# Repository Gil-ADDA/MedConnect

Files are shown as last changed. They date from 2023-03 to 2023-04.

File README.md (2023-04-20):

# MedConnect: A Compact and Efficient Pill Organizer for Seniors

## Introduction

The purpose of this project is to design and build a set of devices that solve various compounding problems faced by older generations - those being the consumption of prescribed medication in a timely manner, and also frequent isolation from loved ones.

This project serves different purposes for each user. For the patient and their device, it serves as a central device to organize their medication, as well as a reminder to take their medication. For the relative or carer and their device, it provides the knowledge that your loved one or patient is taking their medication properly, or serves as a means to remind them to do so if they forget. For both groups, it provides comfort and connection, illustrating that your loved ones are there for you even when they're physically absent.

The main features of this project are specific to each device. With their device, the patient has the ability to organize a week's worth of medication into daily boxes and, by the act of taking their medication, notify their relative of carer that they have done this. It also has the ability to receive notifications from the relative or carer device and use a buzzer to notify the patient if they have not taken their medication. The relative or carer device has the ability to recieve notifications from the patient device once medication has been taken, as well as remind the patient to take their medication through the push of a button.

## Second Midterm Critique

The feedback our team recieved in our second midterm critique is as follows:
- Change the way the pill boxess will be detected - turning them into the equivilant of a switch, this allowed our team to use a digital pin each for the 7 pill boxes instead of having to split anolog pins between 2 pill boxes in our previous design. 
-  Add communication button to the relative device in order to nudge the user to take medication if they haven't, also lets the user know they're relative or carer is thinking baout them.
- Add rails to the pill box and daily boxes so they fit together correctly.

## Prototyping

MedConnect was created to provide seniors with an effective solution to manage their medication needs, while also providing peace of mind to their family members. Initially, we implemented bare conductive sensors to detect pressure on pill boxes, but we found that they were not accurate enough. We then tried using a 1kg load cell, but it proved to be difficult to measure milligrams precisely. Eventually, we decided to use copper foil to detect each daily pill box. Our original plan involved sliding pill boxes and displaying medication reminders on an LCD screen.

During the development of the first printing, we made several iterations to improve its design and functionality. We received feedback about the initial size and material waste of the first printing, which prompted us to make adjustments to reduce the size of the box while still maintaining ergonomic and practical considerations. The second version of the box was successfully resized to fit comfortably in the hand and allowed for efficient storage of pills, while also being proportional to the copper foils and electrical wires. The third and final version addressed concerns about copper foil damage and the need for sufficient space for magnets to secure the small boxes. These modifications made the box more user-friendly, with improved circuit stability and a secure magnet system. The overall result is a compact and efficient pill organizer that is easy to use and troubleshoot.

Below are images showing the development process of MedConnect from its initial prototype to the final product:

### Drawing of the Pill Organizer
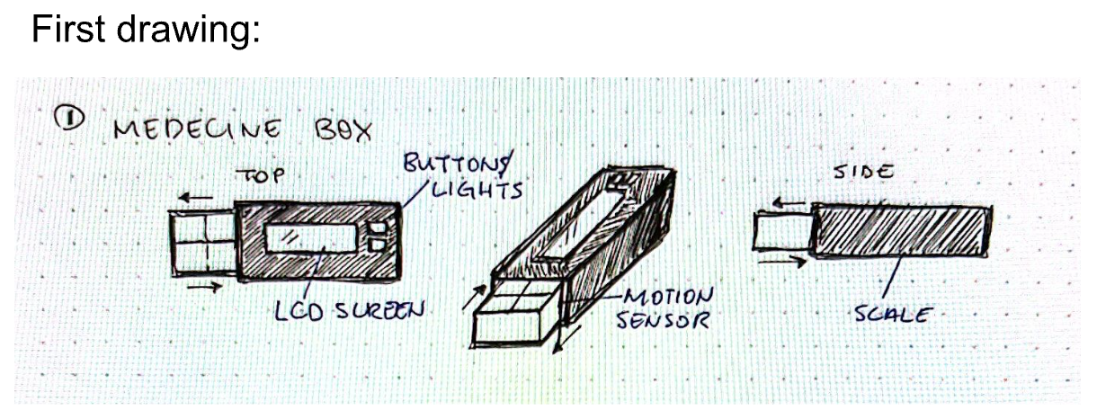
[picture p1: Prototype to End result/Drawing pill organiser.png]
Drawing of the Pill Organizer


### First Prototype - Bare Conductive Sensors
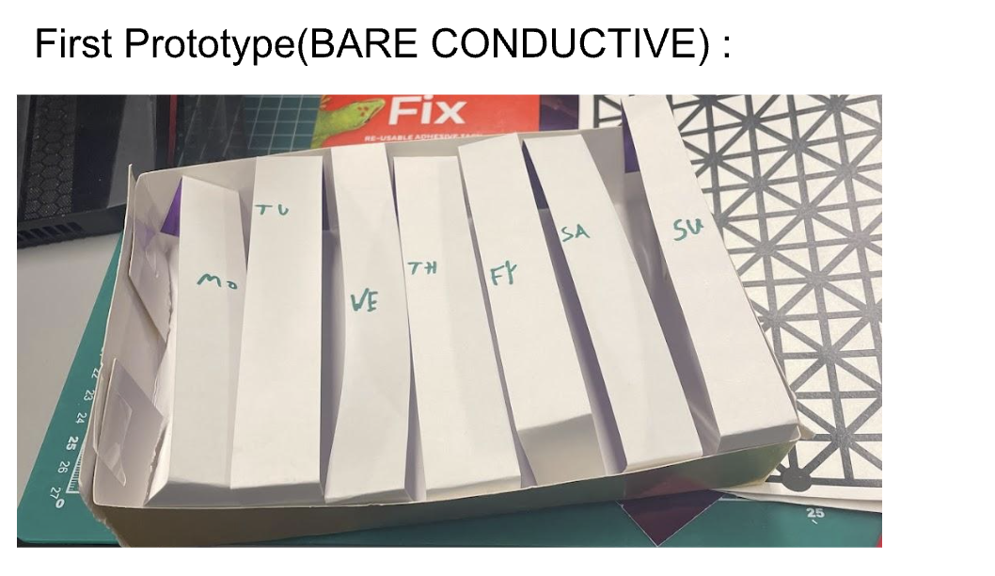
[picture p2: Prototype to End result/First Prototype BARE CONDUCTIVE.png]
First Prototype - Bare Conductive Sensors


### Second Prototype - Copper Foil
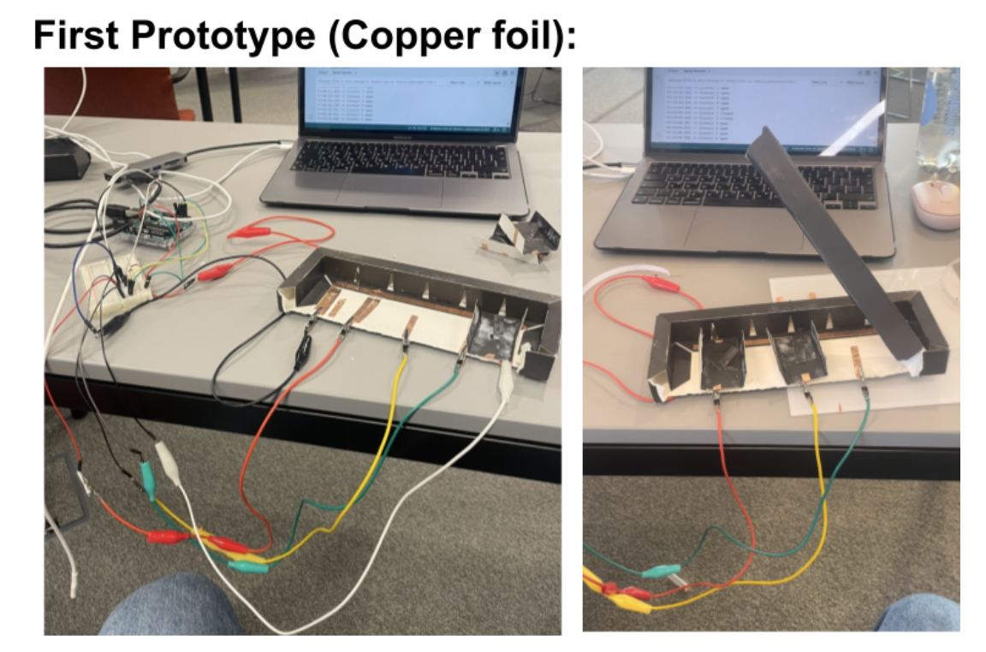
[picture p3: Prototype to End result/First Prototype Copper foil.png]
Second Prototype - Copper Foil


### First 3D Printed Prototype
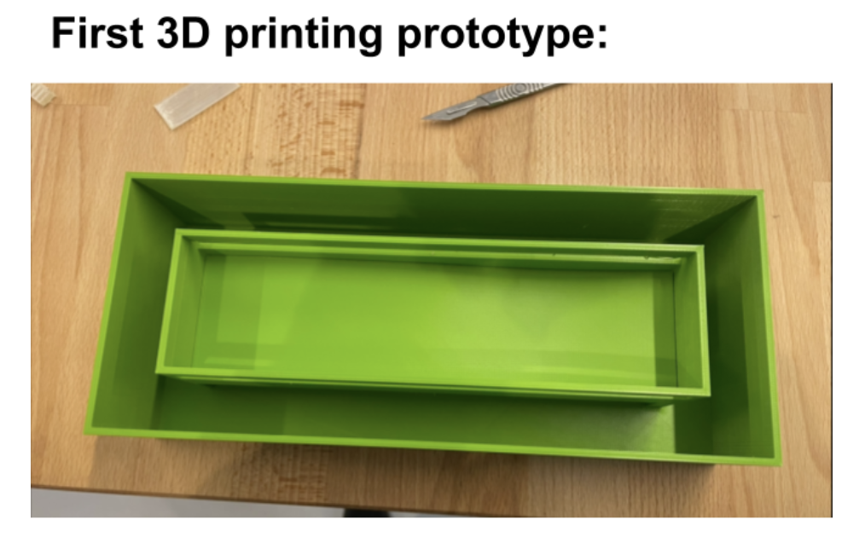
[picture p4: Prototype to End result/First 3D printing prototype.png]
First 3D Printing Prototype


### Second 3D Printed Prototype
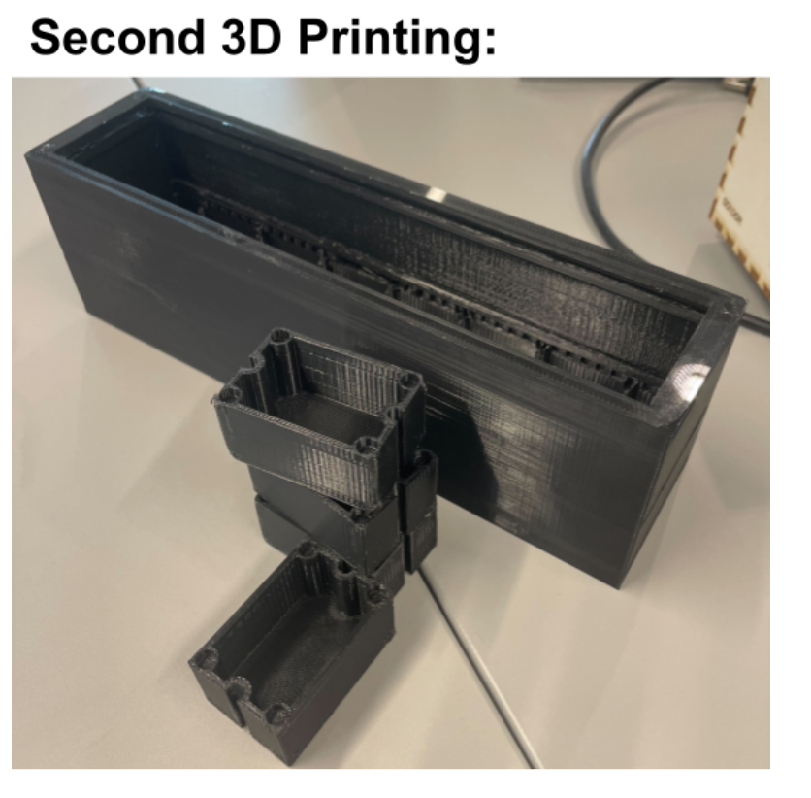
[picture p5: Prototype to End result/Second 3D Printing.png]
Second 3D Printing Prototype


### The Platform for the Circuit
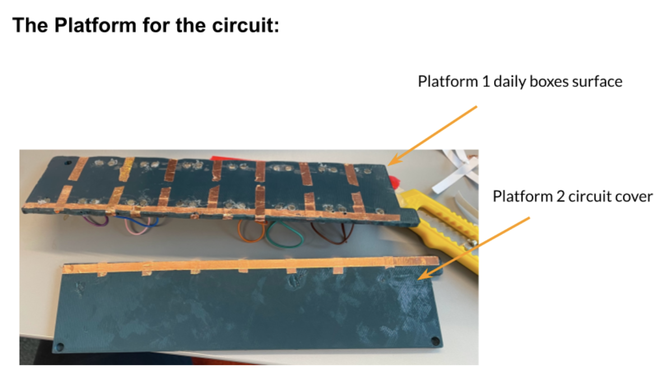
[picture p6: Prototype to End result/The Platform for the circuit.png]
The Platform for the Circuit


### PCB Blueprint
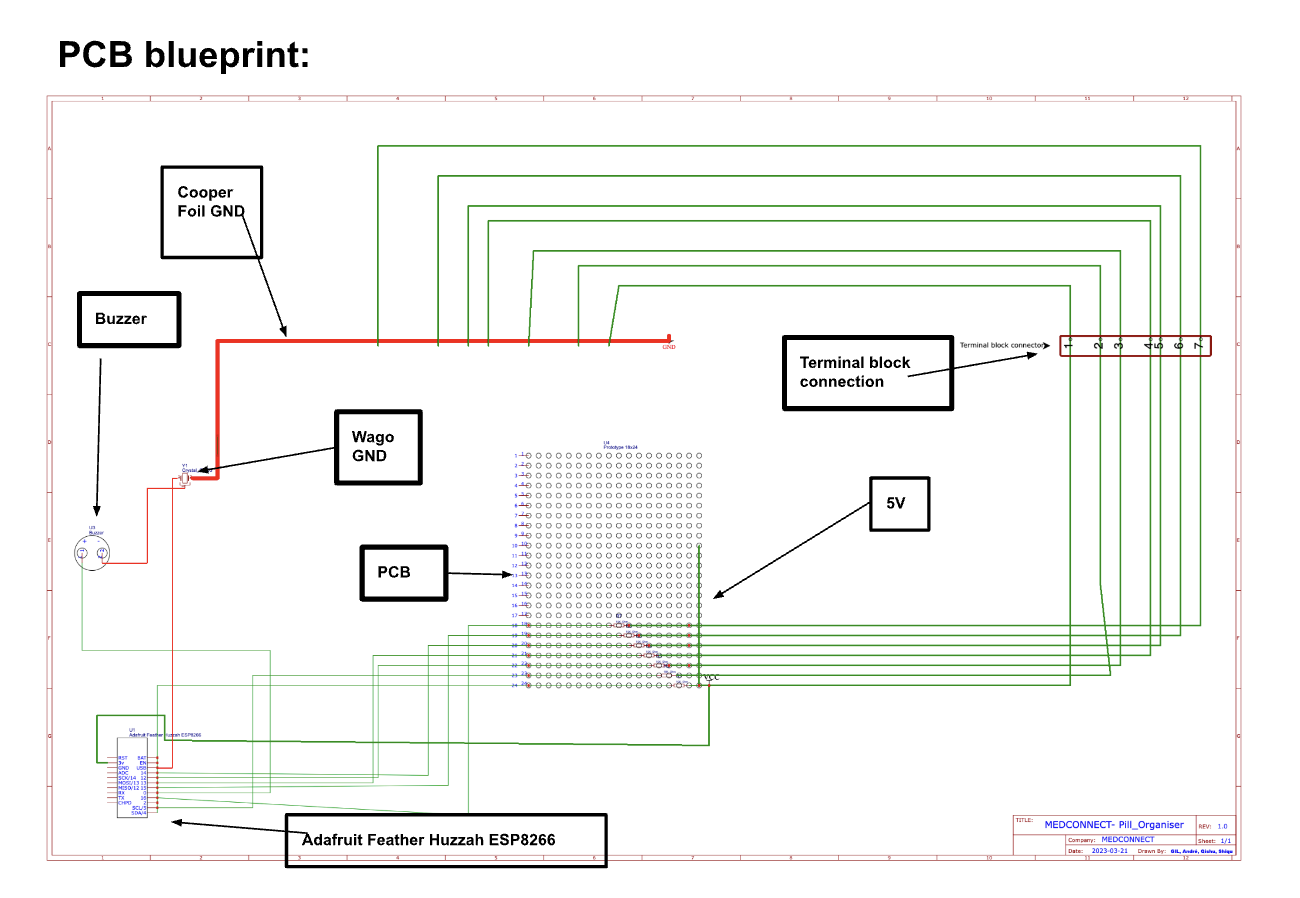
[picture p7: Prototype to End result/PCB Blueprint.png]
PCB Blueprint


### End Result - 3D Printed Pill Organizer
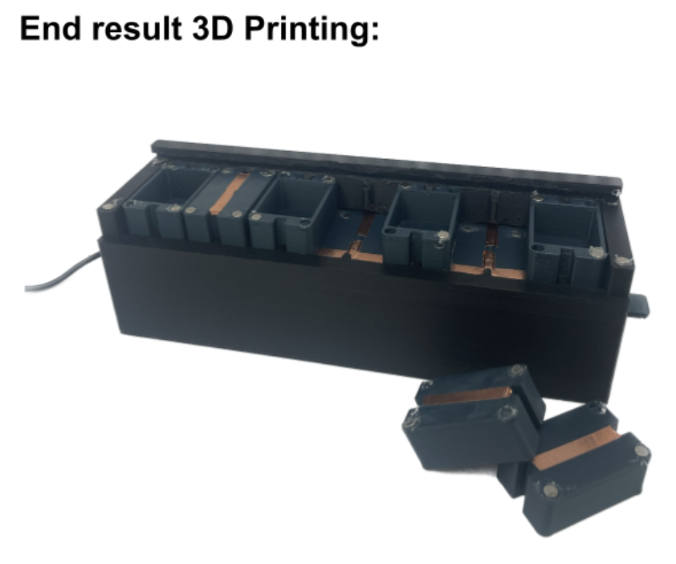
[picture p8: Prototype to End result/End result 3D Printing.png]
End Result - 3D Printed Pill Organizer


### Drawing of the Relative Device
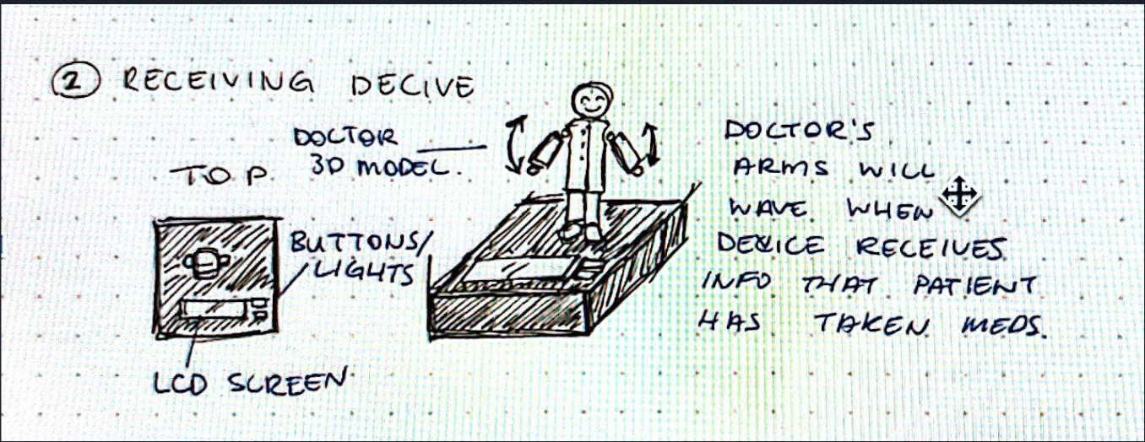
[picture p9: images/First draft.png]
Drawing of the relative device


### Laser Cut design - Relative Device 
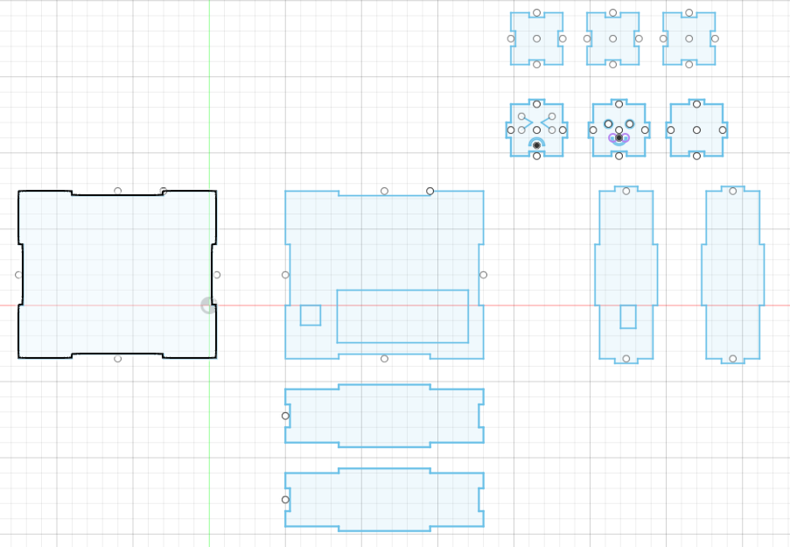
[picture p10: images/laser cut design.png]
Laser cut design


### End Result - Relative Device
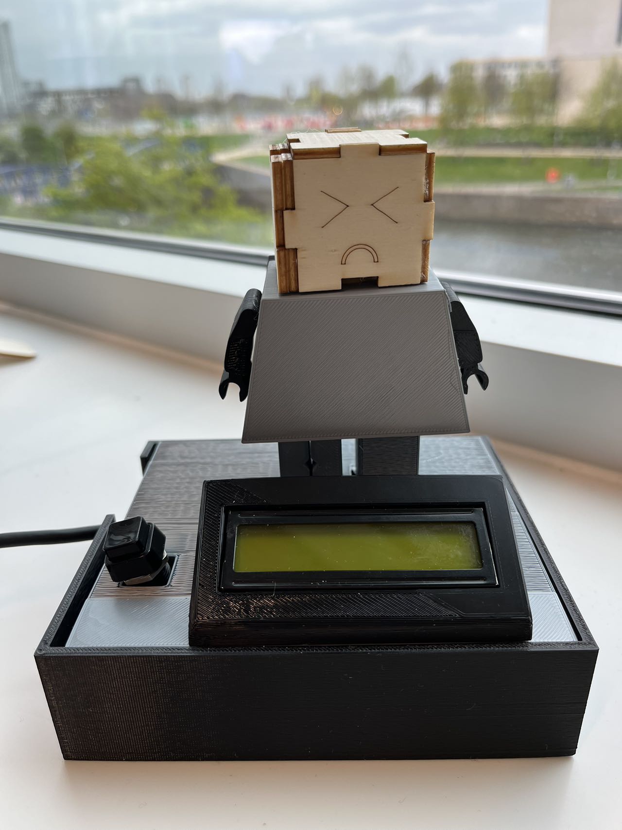
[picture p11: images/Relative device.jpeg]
Relative device


## Hardware and Software Components
A list of the hardware and software components used in the project, including microcontrollers, sensors, and libraries.

### Pill Organizer

**Hardware**
- Adafruit Feather Huzzah ESP8266
- Piezo Buzzer 
- Copper wire
- Copper foil
- Magnets
- USB power cord
- PLA filament
- Acrylic sheet

**Software**
- ezTime library
- PubSubClient library
- ArduinoJson library
- ESP8266 Wi-Fi library

### Relative Device

**Hardware**
- Adafruit Feather Huzzah ESP8266
- PLA filament
- LCD screen
- Servo motor
- USB power cord
- Copper wire
- Wooden materials

**Software**
- ezTime library
- PubSubClient library
- ArduinoJson library
- ESP8266 Wi-Fi library
- String library
- Wire library
- Servo library
- LiquidCrystal_I2C library

## Design & 3D Models

### Patient Device
medconnect model

### Relative Device
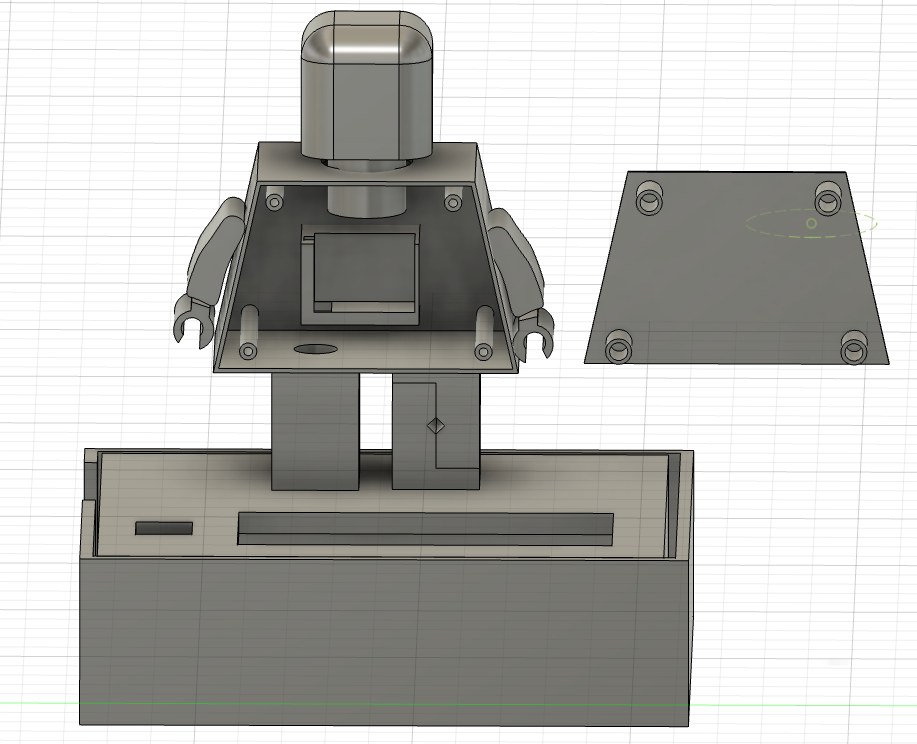
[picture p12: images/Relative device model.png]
Relative device model


## Usage:

### Pill Organizer
Plug in the smart medicine box to a power source using the provided cable.
Fill the compartments with the necessary medication for each day of the week.
The smart medicine box will keep track of the medication schedule and send notifications to the relative device whenever pills are taken or missed.
Receiving Notifications and Sending Reminders
The Medconnect pill organizer is designed to send notifications to the relative device whenever the senior user takes their pills or if they miss their medication. If the senior user misses their medication, the relative device can send a notification to remind them to take their pills. Additionally, the relative device can send a notification to the smart medicine box by pressing a button on the device, activating the buzzer on the smart medicine box to remind the senior user to take their pills.

### Relative Device
The 3D doctor model on the relative device is designed to provide emotional engagement and accountability for the senior user's medication adherence. By default, the doctor has a sad face, but when the senior user takes their pills, the doctor's face turns to a happy expression.There is an lcd screen that can be used to show how much unused medicine is left in the box. Every midnight, the doctor's face returns to the default sad face.

## Specific Features and Functions
The Medconnect pill organizer has several specific features and functions that you may find useful:

- Medication Schedule: The smart medicine box is divided into different compartments for each day of the week, but there are no specific times for taking the medication.
- Notification and Alerts: The smart medicine box is designed to send notifications to the relative device whenever the senior user takes their pills or if they miss their medication. The relative device can also send a notification to remind the senior user to take their pills by activating the buzzer on the smart medicine box.
- Emotional Engagement: The 3D doctor model provides emotional engagement and accountability, strengthening the bond between patients and their families. By default, the doctor has a sad face, but when the senior user takes their pills, the doctor's face turns to a happy expression. Every midnight, the doctor's face returns to the default sad face.
- Easy to Use: The Medconnect pill organizer is designed to be easy to use, with clearly labeled compartments and a simple interface.
- Compact Size: The smart medicine box is compact and can be easily stored on a shelf or countertop.

## Troubleshooting
Information on how to troubleshoot common issues or errors that may occur while using the device.

 ### Pill Orgnanizer
 - One issue someone may face with with the pill organizer is the detection of an open circuit even when a daily box has been placed back into it's slot. This is is due to insufficient contact between the box and the main body of the device. To remedy this, simple adjust the box so it sits flush against its base and give it a slight push down into its correct position.
 
 ### Relative Device
 - A problem someone may face is that after pressing a button, that device does not capture the moment of the button press, so it may result in no feedback from the corresponding device even though the user pressed the button. To solve this problem, try pressing the button a few more times to be able to ensure that the message is definitely received.

## Future work

### Pill Organiser
In the future work, our team would like to add a temperature and humidity sensor to the pill organiser. This addition will help to ensure that the patient is keeping their medication in an ideal environment to maintain its effectiveness. Temperature and humidity information will be displayed on an attached LCD screen for convenient viewing. Our team would also like to include more inclusive means of reminding patients to take their medicine, including a flashing light or possibly push notifications to a patient’s smart device.

### Relative Device
In the future, the use of messaging could be used to enable more to be passed between the two devices than just the alert. More contents could also be added to the LCD display.

Currently, most parts of the family's device are made up of 3D printed materials due to technical limitations, which also leads to high manufacturing costs and the inability to recycle. In the future, recyclable materials could be used instead of 3D printed materials, which would reduce costs and be environmentally friendly at the same time.

## Contributors:

| Product/Responsibility | Members | Activities |
|---|---|---|
| Pill organiser | Gil Adda, André Bourgeois | Prototyping, writing the code for MQTT, buzzer, 7 input pins, design the pill organiser 3D model (fusion), 3D printing (Prusa and Ultimaker), design the circuit and soldering |
| Relative device | Shiqu Gao, Qishu Qian | Writing the code, design 3D model (fusion), 3D printing (Prusa and Ultimaker), laser cutting (fusion), design the circuit and soldering |

## License
This project is licensed under the MIT License.

## References:
A list of any sources or references used in the project.(harvard referneces)

Medication reminder GlowCap goes direct-to-consumer (2009). Available at: https://www.mobihealthnews.com/3888/medication-reminder-glowcap-goes-direct-to-consumer.

EllieGrid (no date) The Smart Pill Organizer with Brains & Beauty. Available at: https://elliegrid.com/.

Sagely (2018b) Daily Pill Organizers and Pill Reminder App | Sagely. Available at: https://www.livesagely.com/.

Abdul Minaam, D.S. and Abd-ELfattah, M. (2018). Smart drugs:Improving healthcare using Smart Pill Box for Medicine Reminder and Monitoring System. Future Computing and Informatics Journal, 3(2), pp.443–456. doi:10.1016/j.fcij.2018.11.008.

Good Night Lamp, Source: https://www.designswarm.com/good-night-lamp/ (Retrieved on 23/01/2023)

Rosli, E. and Husaini, Y. (2018). Design and Development of Smart Medicine Box. IOP Conference Series: Materials Science and Engineering, 341, p.012004. doi:10.1088/1757-899x/341/1/012004.

Ughade, S.M. (2021). Low Powered IOT Enable Smart Medicine Pill Box Using ESP 8266. International Journal for Research in Applied Science and Engineering Technology, 9(VII), pp.3804–3808. doi:10.22214/ijraset.2021.36930.

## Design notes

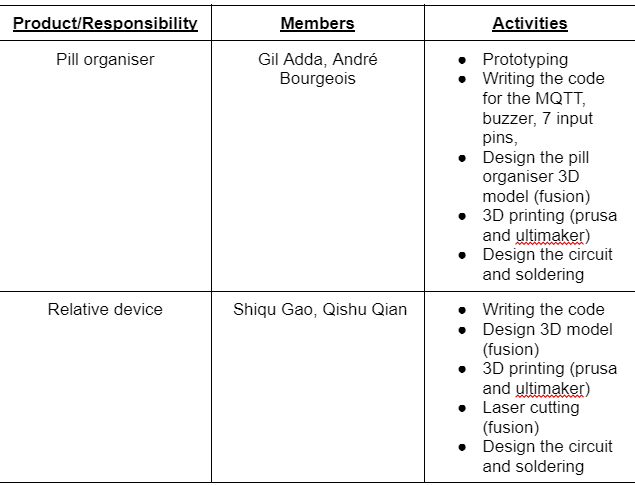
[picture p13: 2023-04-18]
images/Team.png

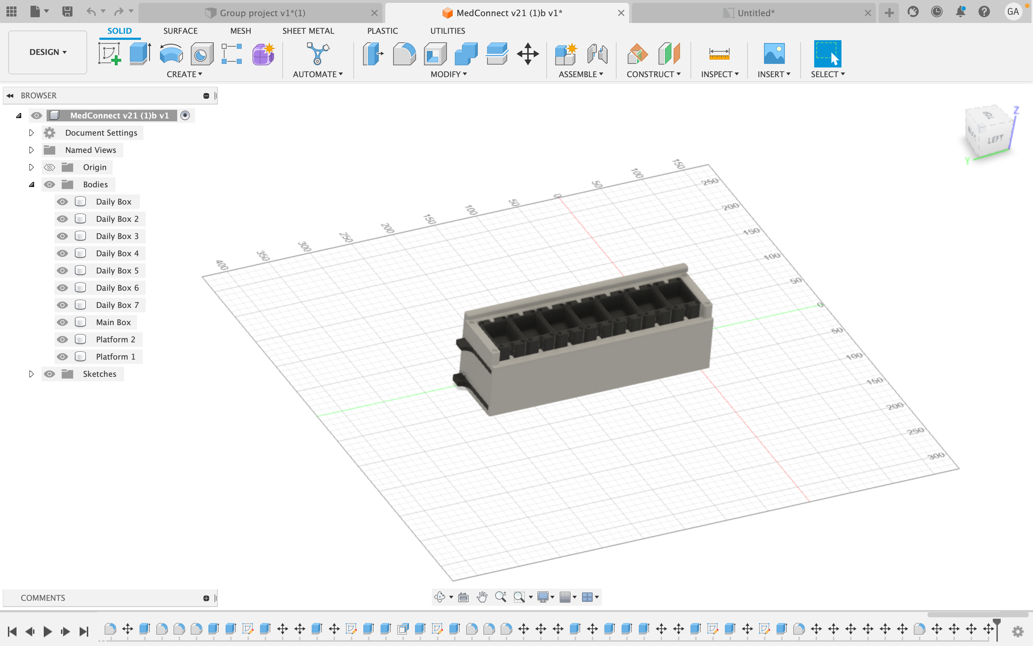
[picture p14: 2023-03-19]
images/Screenshot 2023-03-16 at 16.17.45.png

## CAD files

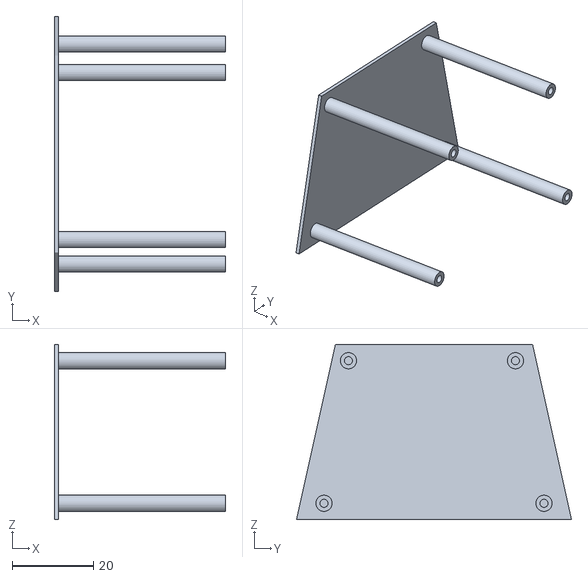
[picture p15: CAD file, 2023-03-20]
3d model/base.stl
42.0 x 67.5 x 43.0

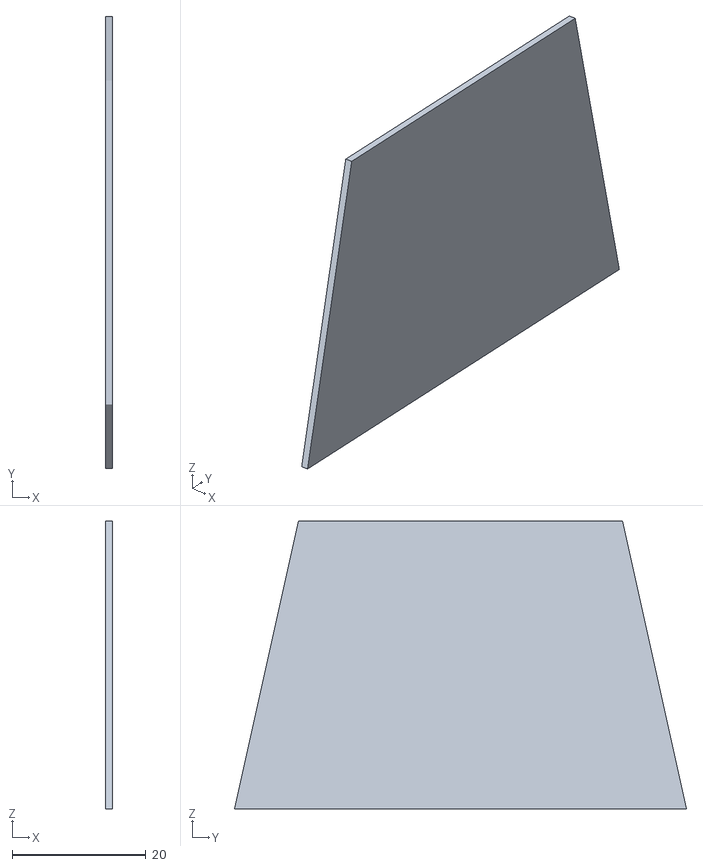
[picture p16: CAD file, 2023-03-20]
3d model/body5.2.stl
1.00 x 67.5 x 43.0

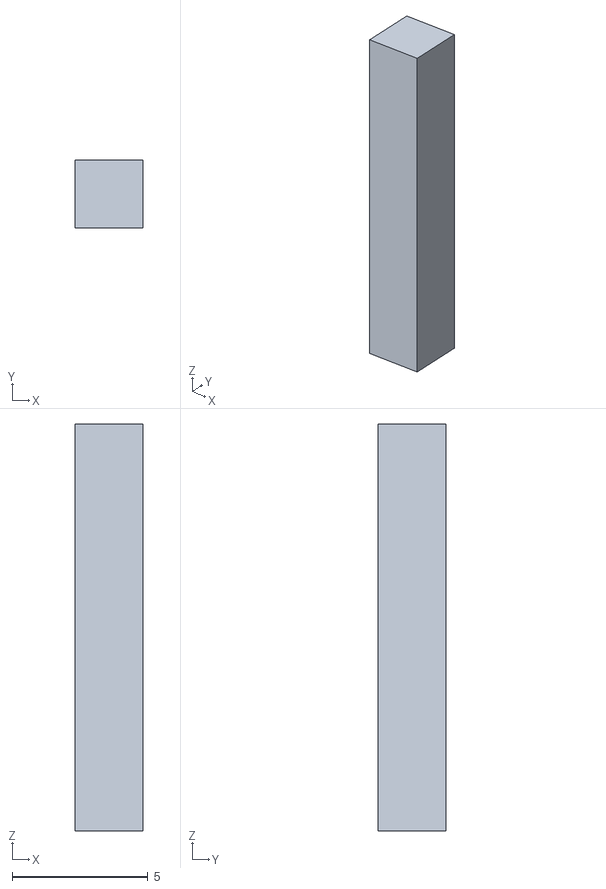
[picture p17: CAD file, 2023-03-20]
3d model/sunmao3.stl
2.50 x 2.50 x 15.0

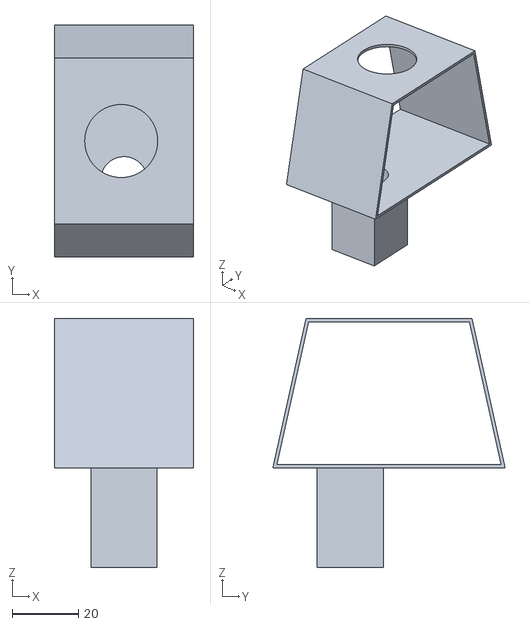
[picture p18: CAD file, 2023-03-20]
3d model/body5.0.stl
42.0 x 70.0 x 75.0

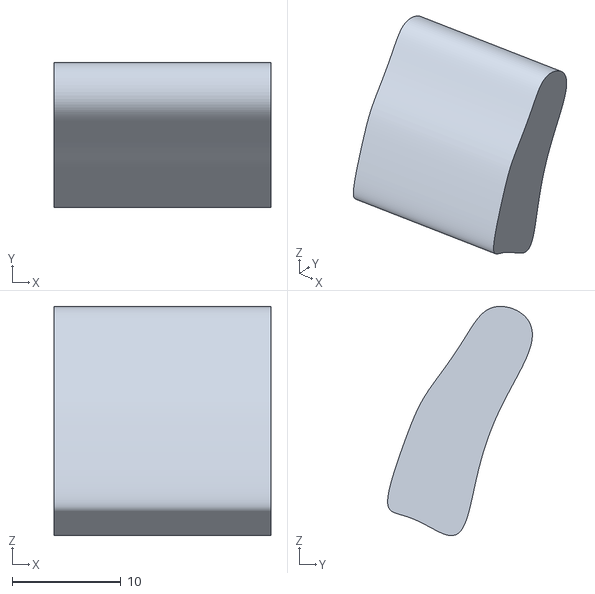
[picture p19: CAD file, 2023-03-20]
3d model/arm.stl
20.0 x 13.3 x 21.1

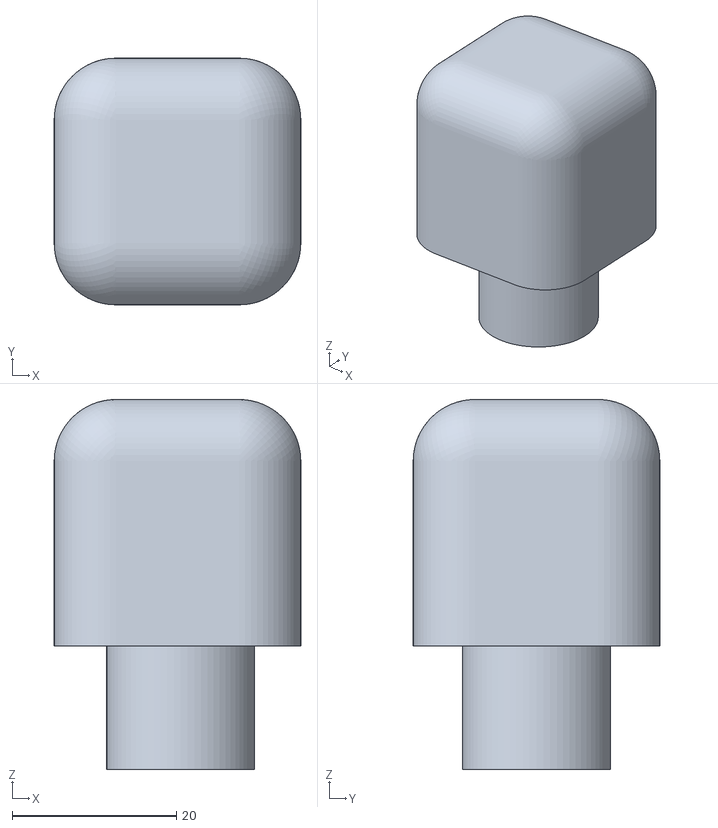
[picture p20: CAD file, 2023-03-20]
3d model/head8.0.stl
30.0 x 30.0 x 45.0

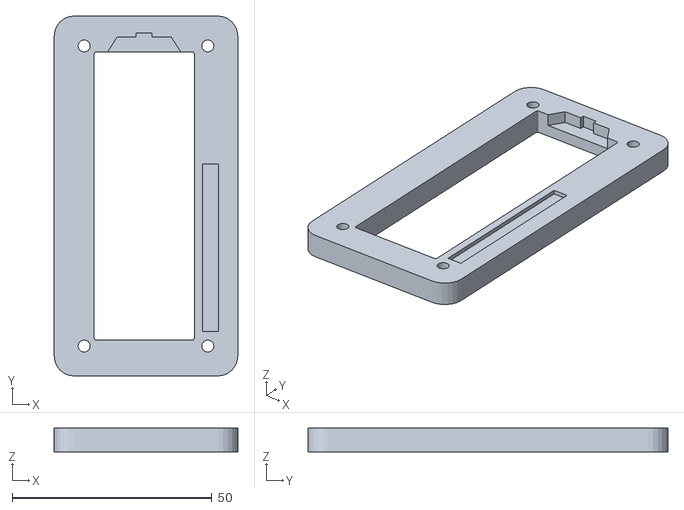
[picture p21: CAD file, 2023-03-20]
3d model/LCD_Outline.stl
46.0 x 90.2 x 6.00

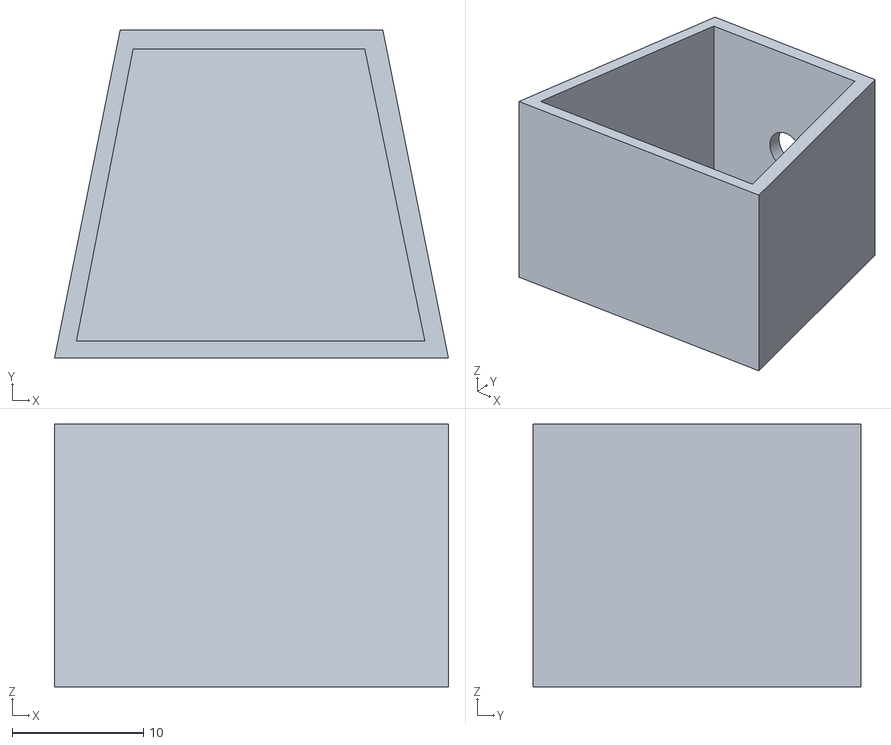
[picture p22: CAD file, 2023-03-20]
3d model/body.stl
30.0 x 25.0 x 20.0

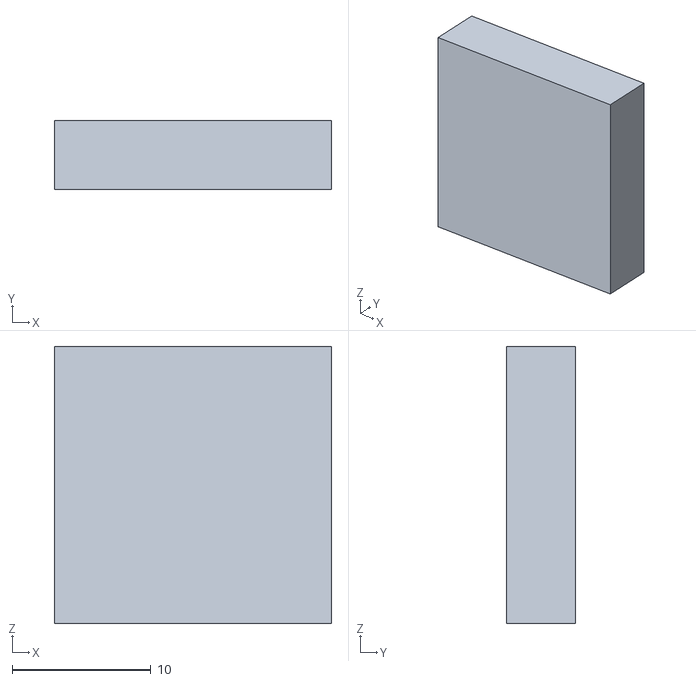
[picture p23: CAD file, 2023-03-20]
3d model/leg2.stl
20.0 x 5.00 x 20.0

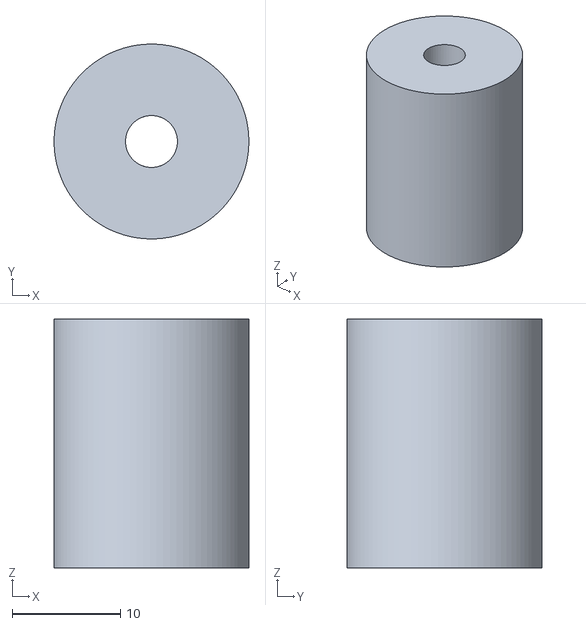
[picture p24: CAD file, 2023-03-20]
3d model/bozi.stl
18.0 x 18.0 x 23.0

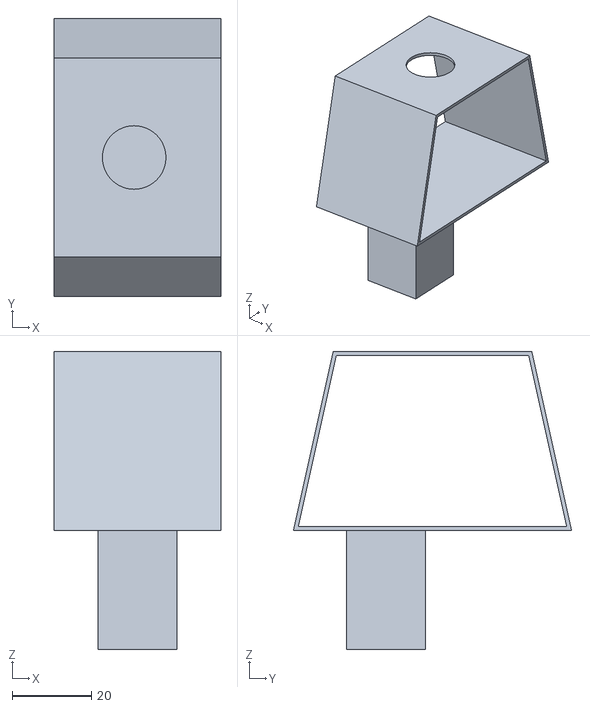
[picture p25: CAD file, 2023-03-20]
3d model/body5.4.stl
42.0 x 70.0 x 75.0

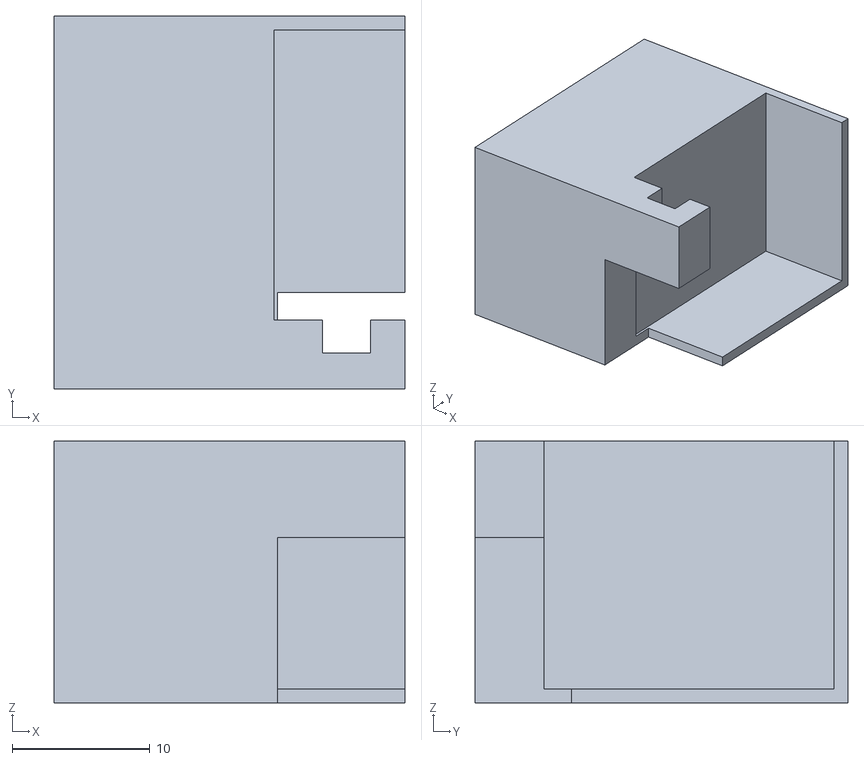
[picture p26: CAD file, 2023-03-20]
3d model/body5.1.stl
25.5 x 27.1 x 19.0

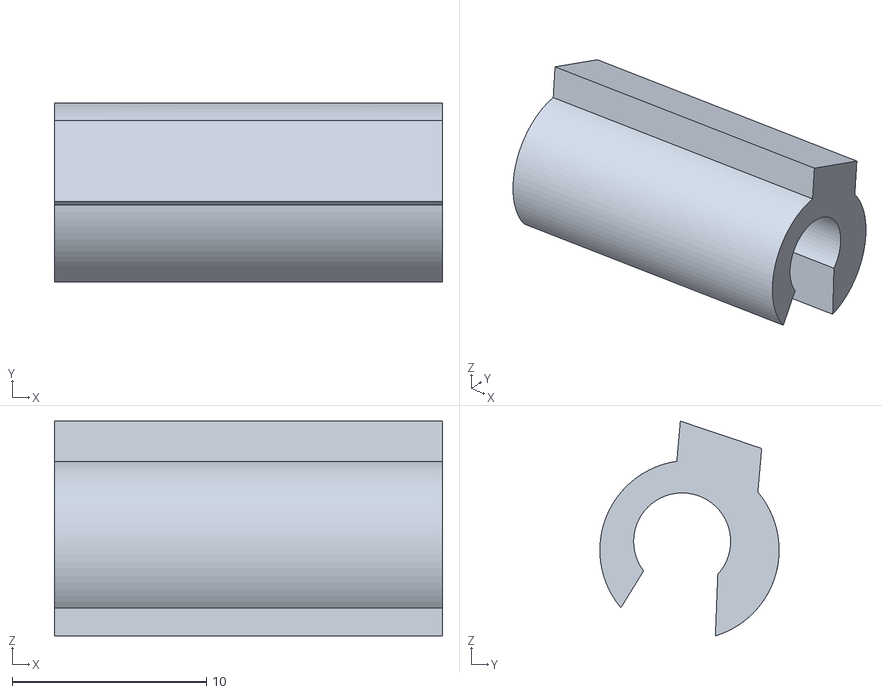
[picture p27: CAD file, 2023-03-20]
3d model/hand.stl
20.0 x 9.24 x 11.1

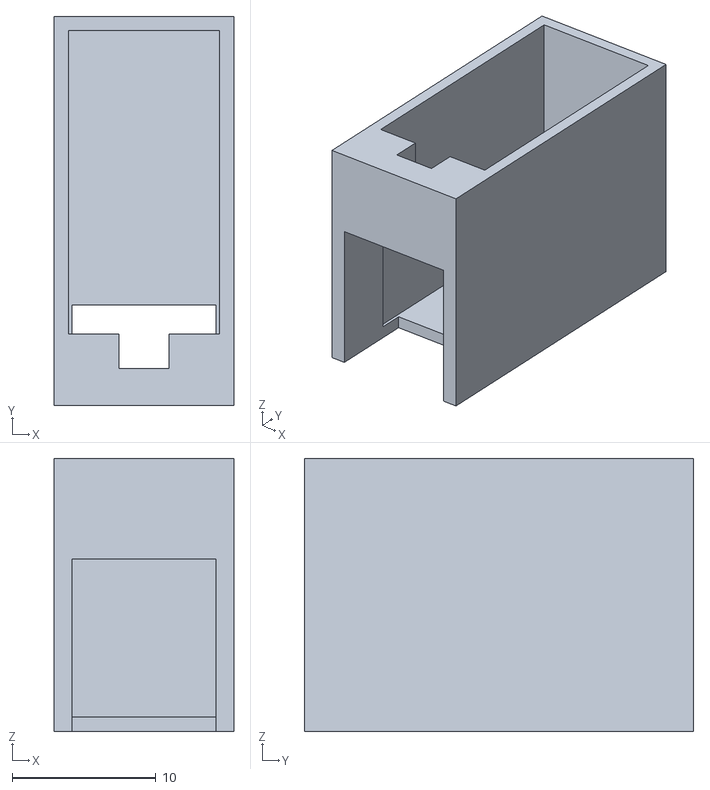
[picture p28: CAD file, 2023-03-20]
3d model/holder.stl
12.5 x 27.1 x 19.0

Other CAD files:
3d model/body2.stl
3d model/body5.6.stl
3d model/head.stl
3d model/body5.3.stl
3d model/leg1.stl
3d model/sunmao2.0.stl
3d model/top.stl

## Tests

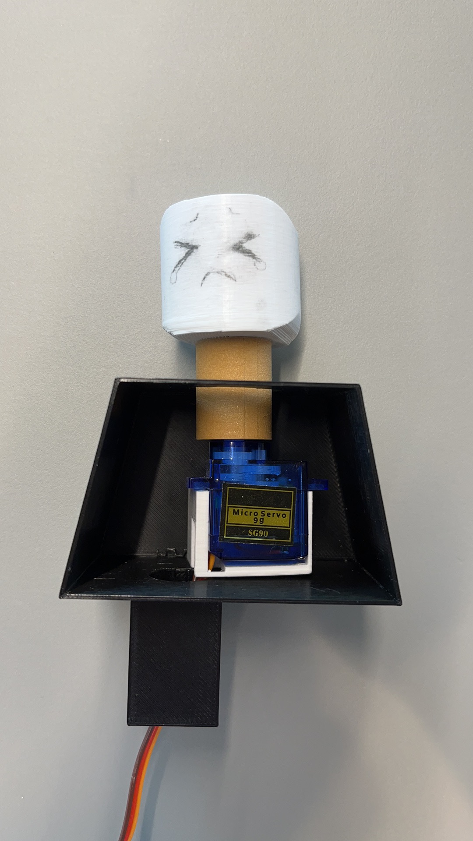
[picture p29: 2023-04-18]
images/Relative device test.jpeg

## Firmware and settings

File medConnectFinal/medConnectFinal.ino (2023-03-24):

// import libraries
#include <ezTime.h> // time
#include <PubSubClient.h> // pub/sub to mqtt
#include <ArduinoJson.h> // send json data
//#include <DHT.h> // dht temp/hum sensor
//#include <DHT_U.h> // dht temp/hum sensor
#include <ESP8266WiFi.h> // connect nodemcu to wifi
#include "arduino_secrets.h" // contains sensetive data like passwords


// set the dht type
//#define DHTTYPE DHT22   // DHT 22  (AM2302), AM2321

// Sensors and Buzzer
// uint8_t DHTPIN = A1;   // for dht on pin analog 4 of the nodemcu
uint8_t BUZZERPIN = 16;   // for buzzer on pin analog 2 of the nodemcu
uint8_t BOXPINS[] = {14, 12, 13, 5, 0, 4, 2}; // array of input bins for box circuits
float Temperature;
float Humidity;
//DHT dht(DHTPIN, DHTTYPE);   // Initialize DHT sensor.

// Wifi and MQTT
const char* ssid     = SECRET_SSID;
const char* password = SECRET_PASS;
const char* mqttuser = SECRET_MQTTUSER;
const char* mqttpass = SECRET_MQTTPASS;
const char* mqtt_server = "mqtt.cetools.org";
const char* topic = "student/ucfnbou/medConnected";

WiFiClient espClient;
PubSubClient client(espClient);
long lastMsg = 0;
char msg[50];
int value = 0;
int past = 0;

// Date and time
Timezone GB;

void setup() {
  // open serial connection for debug info
  Serial.begin(115200);
  delay(1000);

  // start DHT sensor
  //pinMode(DHTPIN, INPUT);
  //dht.begin();

  // start buzzer
  pinMode(BUZZERPIN, OUTPUT);

  // set box pins
  for (int i = 0; i < 7; i++) {
      pinMode(BOXPINS[i], INPUT_PULLUP);
    }

  // run initialisation functions
  startWifi();
  syncDate();

  // start MQTT server
  client.setServer(mqtt_server, 1884);
  client.setCallback(callback);
}

void loop() {

  if (minuteChanged()) {
    sendMQTT();
    Serial.println(GB.dateTime("H:i:s")); // UTC.dateTime("l, d-M-y H:i:s.v T")
  }
  
  client.loop();
}

void startWifi() {
  // start by connecting to a WiFi network
  Serial.println();
  Serial.print("Connecting to ");
  Serial.println(ssid);
  WiFi.begin(ssid, password);

  // check to see if connected and wait until you are
  while (WiFi.status() != WL_CONNECTED) {
    delay(500);
    Serial.print(".");
  }
  Serial.println("");
  Serial.println("Wi-Fi connected");
  Serial.print("IP address: ");
  Serial.println(WiFi.localIP());
}

void syncDate() {
  // get real date and time
  waitForSync();
  Serial.println("UTC: " + UTC.dateTime());
  GB.setLocation("Europe/London");
  Serial.println("London time: " + GB.dateTime());

}

void sendMQTT() {
  //reconnect if the client is no connected
  if (!client.connected()) {
    reconnect();
  }
  client.loop();

  // get data
  // Temperature = dht.readTemperature(); // Gets the values of the temperature
  // default temperature value for debugging without a dht sensor
  // Temperature = 1;
  // Serial.print("Publish message for t: ");
  // Serial.println(msg);

  // Humidity = dht.readHumidity(); // Gets the values of the humidity
  // default humidity value for debugging without a dht sensor
  // Humidity = 1;
  // Serial.print("Publish message for h: ");
  // Serial.println(msg);

  int openCount = 0; // count number of open circuits
  // iterate through pins and read state
  // start; stop; step
  for (int i = 0; i < 7; i++) {
    // state is TRUE or FALSE based on pin reading at i
    // TRUE if LOW; FALSE if HIGH
    bool state = digitalRead(BOXPINS[i]) == LOW;
    // if state = TRUE
    if (state) {
      Serial.print("Circuit ");
      Serial.print(i + 1);
      Serial.println(" is closed");
    } else { // if state = FALSE
      Serial.print("Circuit ");
      Serial.print(i + 1);
      Serial.println(" is open");
      // increment the count of open circuits
      openCount++;
    }
  }
  Serial.print("Number of open circuits: ");
  Serial.println(openCount);
  delay(500);

  // put data in json document
  // create json document called docSend
  StaticJsonDocument<256> docSend;
  // add temperature object with value of temperature variable
  // docSend["Temperature"] = Temperature;
  // add humidity object with value of humidity
  // docSend["Humidity"] = Humidity;
  // add open circuit count
  docSend["Number"] = openCount;

  // using buffer helps to allocate memory quicker
  char buffer[256];
  // serialize json document
  serializeJson(docSend, buffer);
  // publish json document
  client.publish("student/ucfnbou/medConnect", buffer);
}

void callback(char* topic, byte* payload, unsigned int length) {
  Serial.print("Message arrived [");
  Serial.print(topic);
  Serial.print("] ");
  for (int i = 0; i < length; i++) {
    Serial.print((char)payload[i]);
  }
  Serial.println();

  StaticJsonDocument<256> docRec;  // Allocate the JSON document
  deserializeJson(docRec, payload, length);// Deserialize the JSON document
  String myString = String((char*)payload);
  int myValue = docRec["times"];
  //char json[length] = myString;
  Serial.print(myValue);
  Serial.println();

  if (myValue != past) {
    for (int i = 0; i < 5; i++) {
      Serial.print("buzz ");
      tone(BUZZERPIN, 600);
      delay(2000);
      noTone(BUZZERPIN);
    }
  past = myValue;
  }
}

void reconnect() {
  // Loop until we're reconnected
  while (!client.connected()) {
    Serial.print("Attempting MQTT connection...");
    // Create a random client ID
    String clientId = "ESP8266Client-";
    clientId += String(random(0xffff), HEX);

    // Attempt to connect with clientID, username and password
    if (client.connect(clientId.c_str(), mqttuser, mqttpass)) {
      Serial.println("connected");
      // ... and resubscribe
      client.subscribe("student/ucfnbou/medConnected");
    } else {
      Serial.print("failed, rc=");
      Serial.print(client.state());
      Serial.println(" try again in 5 seconds");
      // Wait 5 seconds before retrying
      delay(1000);
    }
  }
}

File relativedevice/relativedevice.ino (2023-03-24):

#include <ArduinoJson.h>
#include <ArduinoJson.hpp>
#include <ezTime.h>
#include <ESP8266WiFi.h>
#include <ESP8266WebServer.h>
#include <PubSubClient.h>
#include <String.h>
#include "arduino_secrets.h"
#include <LiquidCrystal_I2C.h>
#include <Wire.h> 
#include <Servo.h>

int totalColumns = 16;
int totalRows = 2;
Servo myservo;


LiquidCrystal_I2C lcd(0x27, totalColumns, totalRows);

const char* ssid = SECRET_SSID;
const char* password = SECRET_PASS;
const char* mqttuser = SECRET_MQTTUSER;
const char* mqttpass = SECRET_MQTTPASS;

const int buttonPin = 13;
int times = 0;

String current_time;
String past_time;
int a;
int A1;
int a2;
int b = 0;
int tem;
int tem1;
int hum;
int hum1;
Timezone GB;
ESP8266WebServer server(80);
const char* mqtt_server = "mqtt.cetools.org";
WiFiClient espClient;            //handle wifi messages
PubSubClient client(espClient);  //handle MQTT messages, pass wificlient to connect
StaticJsonDocument<200> doc;     // Allocate the JSON document
void setup() {
  // put your setup code here, to run once:
  Serial.begin(115200);
  delay(100);

  startWifi(); 
  startWebserver(); 
  pinMode(buttonPin, INPUT_PULLUP);
  myservo.attach(14);
  lcd.init(); 
  lcd.backlight(); // use to turn on and turn off LCD back light
  // Set button as interrupt, assign interrupt function and set RISING mode

  // while (WiFi.status() != WL_CONNECTED) {
  //   delay(500);
  //   Serial.print(".");
  // }
  //waitForSync();

  Serial.println("UTC: " + UTC.dateTime());

  GB.setLocation("Europe/London");
  Serial.println("London time: " + GB.dateTime());  

  // start MQTT server
  client.setServer(mqtt_server, 1884);
  client.setCallback(callback);
}

void detectButton() {
      delay(100);
      if(digitalRead(buttonPin) == LOW){
        //Print when button pressed
       Serial.println("Button pressed");
              // Current time
        times = times+ 1;
      }

    
}

void startWifi() {
  // connecting to a WiFi network
  Serial.println();
  Serial.print("Connecting to ");
  Serial.println(ssid);
  WiFi.begin(ssid, password);

  // when not connected keep trying until you are
  while (WiFi.status() != WL_CONNECTED) {
    delay(500);
    Serial.print(".");
  }

  //Exit the while loop means have a connection
  Serial.println("");
  Serial.println("WiFi connected");
  Serial.print("IP address: ");
  Serial.println(WiFi.localIP());  //IP address of Huzzah
}

void startWebserver() {
  // when connected and IP address obtained start HTTP server
  server.begin();
  Serial.println("HTTP server started");
}

void callback(char* topic, byte* payload, unsigned int length) {
  Serial.print("Message arrived [");
  Serial.print(topic);
  Serial.print("] ");
  for (int i = 0; i < length; i++) {
    Serial.print((char)payload[i]);
  }
  Serial.println();

  StaticJsonDocument<1024> doc;  // Allocate the JSON document
  String myString = String((char*)payload);
  //char json[length] = myString;

  deserializeJson(doc, myString);  // Deserialize the JSON document

  // Fetch values.
  int tem = doc["Temperature"];
  int A1= doc["Number"];
  int hum = doc["Humadity"];

  tem1 = tem;
  hum1 = hum;
  a2 = A1;

  Serial.println(a2);
  Serial.println(tem1);

  // b = away_score;
  // current = finished;
}

void reconnect() {
  // Loop until we're reconnected
  while (!client.connected()) {
    Serial.print("Attempting MQTT connection...");
    // Create a random client ID
    String clientId = "ESP8266Client-";
    clientId += String(random(0xffff), HEX);

    // Attempt to connect with clientID, username and password
    if (client.connect(clientId.c_str(), mqttuser, mqttpass)) {
      Serial.println("connected");
      client.subscribe("student/ucfnbou/medConnect");  //subscribe to the topic
    } else {
      Serial.print("failed, rc=");
      Serial.print(client.state());
      Serial.println(" try again in 5 seconds");
      // Wait 5 seconds before retrying
      delay(5000);
    }
  }
}


void sendMQTT() {
  //reconnect if the client is no connected
  if (!client.connected()) {
    reconnect();
  }
  client.loop();
  // Temperature = 1;
  // put data in json document
  // create json document called docSend
  StaticJsonDocument<256> docSend;
  // add temperature object with value of temperature variable
  docSend["times"] = times;
  // using buffer helps to allocate memory quicker
  char buffer[256];
  // serialize json document
  serializeJson(docSend, buffer);
  // publish json document
  client.publish("student/ucfnbou/medConnected", buffer);
}






void testTime(){
  current_time = GB.dateTime("d-M-y");
 //Serial.println(current_time);  
}

void drawlcd1(){
  lcd.setCursor(0, 0);
  lcd.print(a2);
  lcd.setCursor(0,1);
  lcd.print("box is left.");
  delay(1000);
  lcd.clear(); 
}



void servo1() {
  myservo.write(-90);
}

void servo2(){
  myservo.write(180);
}
void loop() {
  // put your main code here, to run repeatedly:
  server.handleClient();      //?
  if (!client.connected()) {  //check if connected to MQTT
    reconnect();
  }

  client.loop();
  testTime();
  if(current_time != past_time){
 // servo reset
 servo1();
  }
  if (a2 != b && a2 != 0){
//servo run    and b=a
  servo2();
  b = a2;
  }
  if (a2 == 0){
    b = 0;
  }
  // if (a2 == 0){
  //   servo1();
  // }
  past_time = current_time;
  detectButton();
  sendMQTT();
  delay(1000);
  drawlcd1();
}

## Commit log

2023-02-27 adding the code for 2 sensors
2023-03-17 Add files via upload
    arduino file to send data from nodemcu to mqtt in json format
2023-03-24 fixing the buzzer code
    [all-code-for-med copy.ino, medConnectFinal.ino]
2023-04-19 UPLOAD IMAGES OF THE PROTOTYPE PROCESS
2023-04-19 Rename Prototype to End result to Prototype to End result/IMAGES
2023-04-19 adding the images and titels of the prototype process
